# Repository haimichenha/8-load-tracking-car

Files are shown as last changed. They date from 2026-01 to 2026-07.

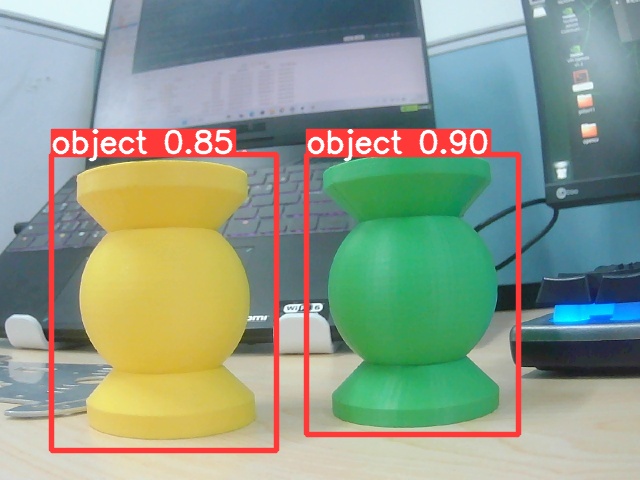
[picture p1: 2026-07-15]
ZET6 HAl/lidar_car/yolov5/runs/detect/exp12/compare.jpg

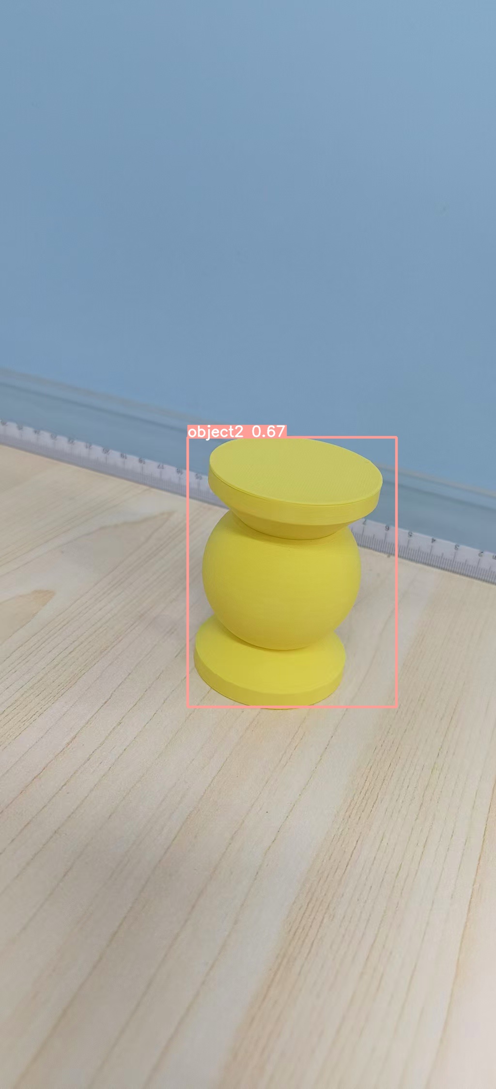
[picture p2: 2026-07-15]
ZET6 HAl/lidar_car/yolov5/runs/detect/exp6/1.jpeg

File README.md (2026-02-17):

# 八路循迹智能小车

基于 STM32F103ZET6 的八路红外循迹智能小车，采用双环 PID 闭环控制（循迹 PD 外环 + 速度 PI 内环），实现高速稳定循线、弯道自适应减速、超声波避障等功能。Keil uVision5 工程，标准库开发。

---

## 目录

- [器件材料表](#器件材料表)
- [功能特性](#功能特性)
- [项目结构](#项目结构)
- [开发历程](#开发历程)

---

## 器件材料表

### 核心控制

| 器件 | 型号/规格 | 说明 |
|---|---|---|
| 主控芯片 | STM32F103ZET6 | Cortex-M3, 72MHz, 512KB Flash, 64KB RAM |
| 小车底盘 | 定制亚克力/铝合金 | 精心挑选孔位，适配各模块安装 |

### 传感器模块

| 器件 | 型号/规格 | 说明 |
|---|---|---|
| 循迹传感器 | 亚博智能八路红外 | GPIO 直读 (PF1-PF4, PF6-PF9)，响应 <1us |
| 超声波模块 | HSR04 | 前方避障测距，非阻塞轮询，60ms 采样周期 |

### 驱动与动力

| 器件 | 型号/规格 | 说明 |
|---|---|---|
| 电机 | G310 霍尔编码器电机 | 带 AB 相正交编码器，11PPR，1:20 减速比 |
| 橡胶轮 | 48mm | 配套 G310 电机 |
| 电机驱动 | TB6612FNG | 双路 H 桥驱动，支持 PWM 调速 |

### 显示与交互

| 器件 | 型号/规格 | 说明 |
|---|---|---|
| OLED 显示屏 | 0.96 寸四引脚 | I2C 接口，128x64 分辨率，分帧刷新 |
| 蜂鸣器 | 无源蜂鸣器 | 低电平触发，PWM 驱动，支持 8 种音效 |

### 电源管理

| 器件 | 型号/规格 | 说明 |
|---|---|---|
| 锂电池 | 辰克 2800mAh | 小型号端子，紧凑安装 |
| 降压模块 | MP1584 | 电池电压降至 5V 稳压输出 |

### 辅料与连接件

| 类别 | 明细 |
|---|---|
| 螺丝紧固 | M3 螺丝、铜柱、厚螺母；M2 螺丝、螺母 |
| 连接器 | 2.54mm 排针、排母 |
| 接线 | 杜邦线、面包板、面包板跳线 |
| 被动元件 | 10uF 直插电容、100nF 贴片陶瓷电容、4.7K 上拉电阻、1K 贴片电阻 |
| 指示器件 | 直插 LED（红/绿/指示） |

---

## 功能特性

### 1. 八路循迹：GPIO 高速识别

- 8 路红外传感器通过 GPIO 直接读取（PF1-PF4, PF6-PF9），读取耗时 <1us
- 非线性权重分布：`{-12, -8, -3, -1, 1, 3, 8, 12}`，边缘传感器权重更大，提升弯道灵敏度
- 加权求和计算循迹误差，支持丢线检测与方向推断
- 传感器值：0 = 检测到黑线，1 = 白色/无线

### 2. 双环 PID 闭环控制

- **外环（循迹 PD）**：根据循迹误差计算转向输出
  - 非线性 Kp 调度：误差越大比例增益越强（err=0: 1.0x → err=12+: 4.0x）
  - D 项抑制振荡，防止蛇形走位
  - 基础参数：Kp=12.0，Kd=2.5
- **内环（速度 PI）**：确保左右轮精确跟踪目标速度
  - 位置式 PI 控制，带积分限幅（±200）
  - 参数：Kp=0.15，Ki=0.08
- 控制周期 2ms（500Hz），高频保证响应及时

### 3. 弯道自适应减速

- 根据循迹误差自动调节基础速度：误差越大，速度越低
- 减速曲线：err=2 保持 97% → err=5 降至 77% → err=10 降至 45% → err=15+ 降至 12%
- 直线基础速度 650mm/s，弯道最低 60mm/s，上限 1100mm/s

### 4. 编码器测速与里程

- MG310 霍尔编码器，11PPR x 20 减速比 x 4 倍频 = 880 脉冲/转
- 左电机 TIM2（PA0/PA1），右电机 TIM3（PA6/PA7），硬件正交解码
- 实时输出：转速 RPM、线速度 mm/s、累计距离 mm
- 左轮方向反转补偿（ENCODER_L_INVERT=1）

### 5. 超声波避障（简易实现）

- HSR04 超声波模块，PA9(Trig) / PA10(Echo)
- 非阻塞轮询模式，60ms 周期自动测距

### 6. OLED 双页面显示

- 0.96 寸 OLED，软件 I2C 驱动（PB10/PB11）
- 分帧刷新策略：运行时 1000ms / 待机 800ms，避免 I2C 通信阻塞控制回路
- 双页面切换（短按 PC5）：
  - **循迹实时页**：循迹误差 + 平均速度、目标速度 L/R、PWM L/R、传感器状态条（避障时显示距离）
  - **参数页**：Kp/Kd 值、基础速度、运行计时、超声波距离
- 启动长按进度条动画，终点到达显示完赛时间

### 7. 按键控制与交互

- **PC5 按键**：短按切换 OLED 页面，长按启动/停止循迹（带进度条反馈）
- **PC4 按键**：运行中按下 = 紧急停止；待机时按下 = 循环 LED 亮度档位（4 档：48→30→15→3）
- 软件消抖处理，按键事件队列机制

### 8. LED PWM 亮度控制

- 3 路 LED：PB9（绿）、PE0（红）、PE1（指示）
- PWM 占空比控制亮度，4 档循环（48/30/15/3）
- 运行时 LED 熄灭降低干扰，终点到达触发灯效

### 9. 蜂鸣器多音效提示

- 无源蜂鸣器 PB8，TIM5_CH3 PWM 驱动，支持频率控制
- 8 种内置音效序列：
  - **开机音**：Do-Sol-高Do 欢迎音
  - **激活提示**：短响 1 声（Sol）
  - **1 分钟提醒**：短响 2 声（Mi-Mi）
  - **终点到达**：3 声升调（Do-Mi-Sol）
  - **成功提示**：上升音阶 Do-Mi-Sol-高Do
  - **错误提示**：下降音阶 Sol-Mi-Do
  - **警告提示**：急促四连响（La x4）
  - **按键音**：极短 30ms 响

### 10. 串口调试日志系统

- 运行时日志存储到 RAM（最多 1400 条 LogEntry，约 20 秒数据 @10ms 周期）
- 停车后通过 UART4（115200 波特率）导出 CSV 格式诊断日志
- 每条记录包含：序号、测试编号、时间戳、循迹误差、传感器原始值、左右轮 PWM/速度/目标速度、控制标志位、饱和信息、动态 Kp 倍率等 22 个字段
- 支持多次测试标记（testId），方便分段分析
- 可通过宏 `LOG_ENABLE` 开关日志功能

---

## 项目结构

### 1. 主控入口与调度：`User/main.c`

`main.c` 是当前 V7 版本唯一的运行主流程入口，负责：

- 系统初始化与启动音效
- 按键事件处理（PC5 启停/切页，PC4 急停/亮度档位）
- 2ms 高频控制环（循迹 PD 外环 + 速度 PI 内环）
- 超声波避障状态机
- OLED 双页面渲染
- 运行日志记录

关键时序（主循环内）：

- **控制环**：`2ms`（`if ((nowMs - lastControlMs) >= 2)`）
- **超声波触发**：`60ms`（`OBS_PERIOD_MS`）
- **外设更新**：运行 `100ms` / 待机 `20ms`
- **OLED 刷新**：运行 `1000ms` / 待机 `800ms` / 长按提示 `150ms`
- **运行态节流**：每圈 `Delay_ms(1)`

`main()` 主流程拆解：

1. **初始化阶段**：`SysTick/按键/红外/超声波/OLED/UART4/LED_PWM/蜂鸣器/电机编码器/PI参数` 依次初始化
2. **待机阶段**：允许切页与亮度档位调整，电机保持停止
3. **启动阶段**：PC5 长按进入运行，清零里程/计时/滤波/状态机并打日志分隔标记
4. **运行阶段**：
   - 读取传感器并计算误差（含丢线恢复、终点投票、方向记忆）
   - 计算动态 `Kp` 与动态基础速度
   - 外环 PD 生成转向量，内环 PI 生成左右 PWM
   - 电机输出 + OLED 刷新 + 日志采样
5. **停止阶段**：急停/终点触发后，停止电机并导出日志

### 2. 功能-文件映射（当前主流程）

| 模块 | 主要文件 | 关键实现 | 参数/依据 |
|---|---|---|---|
| 循迹采集 | `Hardware/bsp_ir_gpio.c/.h` | `IR_GPIO_Init`、`IR_GPIO_Read` | GPIOF 8路引脚映射（PF1-PF4, PF6-PF9） |
| 循迹控制 | `User/main.c` | 加权误差、丢线恢复、交叉抑制、动态 Kp、PD 转向 | `SENSOR_WEIGHTS_V5`、`TRACK_KP/KD` |
| 速度环 | `User/main.c` | `PI_Init`、`PI_Compute`、目标速度合成、PWM 输出 | `SPEED_KP/KI`、`INTEGRAL_MAX`、`PWM_MAX/MIN` |
| 电机驱动 | `Hardware/bsp_motor.c/.h` | `Motor_SetSpeedBoth`、方向与PWM映射 | TB6612 管脚与 20kHz PWM |
| 编码器测速 | `Hardware/bsp_encoder.c/.h` | `Encoder_Init`、`Encoder_Update`、`Encoder_GetSpeedMMS` | 11PPR × 20 × 4 倍频、轮径48mm |
| 超声波避障 | `Hardware/HCSR04.c/.h` + `User/main.c` | `HCSR04_Poll`、`HCSR04_StartMeasure`、状态机接管 | `OBS_WARN_CM/OBS_AVOID_CM/OBS_EXIT_CM` |
| OLED 显示 | `Hardware/OLED.c/.h` + `User/main.c` | `OLED_ShowString` 分帧刷新，双页面显示 | `DISPLAY_PAGES=2`，按状态切页 |
| 按键输入 | `Hardware/bsp_key.c/.h`、`bsp_key2.c/.h` | `Key_Scan`、`Key2_GetEvent` | C5短/长按与 C4 事件分离 |
| LED 指示 | `Hardware/bsp_led_pwm.c/.h` | `LED_PWM_Init`、`LED_SetBrightness`、`LED_StartFinishEffect` | 待机4档亮度、终点灯效 |
| 蜂鸣器 | `Hardware/bsp_buzzer.c/.h` | `Buzzer_PlayBeep`、`Buzzer_BeepTriple`、`Buzzer_Update` | 启动/激活/急停/终点提示 |
| 串口日志 | `User/main.c` + `Hardware/bsp_usart.c/.h` | `Log_Add`、`Log_Start/Stop`、`Log_Export`、`UART4_Send_String` | `LOG_ENABLE`、`LOG_PERIOD_MS`、`LOG_MAX_ENTRIES` |

### 2.1 重点文件补充说明（你关心的模块）

- `Hardware/bsp_led_pwm.c/.h`：当前 LED 主实现，负责三路亮度 PWM、亮度档位、终点灯效。
- `Hardware/app_ui.c/.h`：历史 UI 页面框架（含陀螺仪页等），当前 V7 主流程未调用，现行显示逻辑在 `User/main.c` 内直接渲染。
- `Hardware/app_motor.c/.h`：历史运动封装（`Motion_Car_Control`），当前 V7 主流程主要直接走 `bsp_motor + bsp_encoder + main.c 内 PI`。
- `Hardware/bsp_encoder.c/.h`：编码器采样与速度/里程计算，给主循环速度环提供反馈。
- `Hardware/bsp_ir_gpio.c/.h`：循迹输入底层，8 路 GPIO 快速读取。
- `Hardware/bsp_buzzer.c/.h`：蜂鸣器音效状态机，主循环按周期调用 `Buzzer_Update`。
- `Hardware/HCSR04.c/.h`：超声波非阻塞测距，主循环轮询并驱动避障状态切换。

### 3. 参数集中位置（调参入口）

当前版本参数集中在 `User/main.c` 顶部宏区，便于赛道调参：

- **速度环参数**：`SPEED_KP`、`SPEED_KI`、`INTEGRAL_MAX`
- **循迹参数**：`TRACK_KP`、`TRACK_KD`
- **速度边界**：`BASE_SPEED_MMS`、`MIN_SPEED_MMS`、`MAX_SPEED_MMS`
- **避障阈值**：`OBS_WARN_CM`、`OBS_AVOID_CM`、`OBS_EXIT_CM`
- **日志参数**：`LOG_ENABLE`、`LOG_PERIOD_MS`、`LOG_MAX_ENTRIES`

建议调参顺序：

1. 先调速度环（确保左右轮可稳定跟踪目标）
2. 再调循迹环（Kp 响应、Kd 抑振）
3. 最后调避障阈值和基础速度

### 4. 备用/历史模块说明（当前主流程未调用）

以下文件在工程中仍可见，但**当前 V7 主流程未接入**：

- `Hardware/app_ui.c/.h`：旧版多页面 UI 框架（含陀螺仪页）
- `Hardware/app_control.c/.h`：旧版控制状态机框架（含陀螺仪输入接口）
- `Hardware/JY301P.c/.h`、`wit_c_sdk.c/.h`：陀螺仪协议与解析
- `Tracking/HW_I2C/app_irtracking/mpu6050` 等历史模块：旧方案残留

---

## 开发历程

（待补充）

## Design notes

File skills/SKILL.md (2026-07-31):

---
name: stm32f103zet6-d-mission-car
description: "Use when working on the STM32F103ZET6 land-and-air electronic-competition car for D task: gray line tracking, four-wheel TB6612 bring-up, encoders, gyro/radar pose integration, LoRa V2.3 communication, MaixCam coordination boundaries, A-to-B speed coordination, physical start buttons, staged testing, or related documentation. Read before changing car hardware code, mission behavior, pin maps, or test records."
---

# D Task Car Skill

Use this skill for the car-side STM32F103ZET6 project. The competition vehicle
is a line-following vehicle: the primary local guidance sensor is the
eight-channel gray tracking array, not a camera or an assumed lidar-only path.

## Read In This Order

1. Read `references/rules.md` before changing GPIO, TIM, PWM, encoder, UART,
   motor, or gray-tracking code.
2. Read `references/d-mission-car.md` before changing LoRa, Pi pose input,
   task buttons, state-machine behavior, coordination speed, or D-task logic.
3. Read `references/workflow.md` before wiring, flashing, bench testing, field
   testing, or interpreting logs.
4. Read `references/core.md` and `references/docs.md` when resolving source
   conflicts or updating project documentation.
5. Read `references/radar_bigturn_good_baseline_20260515.md` only for
   historical radar tuning; it never defines the current pin map or protocol.

## Mandatory Decisions

State the active mode before editing or flashing:

- `BENCH_FOUR_WHEEL`: lifted-wheel TB6612 qualification. The gray interface is
  intentionally disabled even though rear STBY is now on PB9.
- `COMPETITION_LINE_FOLLOW`: the gray module owns `PC0/PC1/PC2` as
  `AD0/AD1/AD2` address outputs and `PG0` as the selected digital `OUT`
  input. PG1 is unused. Scan and map all eight heads before controller work.

Never claim the unresolved ADC channels form an eight-position decode. Resolve
physical output mapping, thresholds, safety defaults, and documentation together.

## Operating Rules

1. Keep the car moving after a valid task request; LoRa ACKs, telemetry loss,
   and ground-station display state do not independently stop line following.
2. Start a D-task request only from the physical button on the car. The ground
   station is display and preflight-calibration only during the task.
3. Use encoder speed feedback and gyro yaw correction as assistance around the
   gray tracking controller. Do not replace the gray array with inferred pose
   or radio commands.
4. Choose A-to-B speed from measured path time with margin below the required
   15 s. Other verified sections may be faster, but only after the line,
   encoder, and braking behavior have been tested at that speed.
5. Treat `F:\keil5\stm\ZET6 HAl\lidar_car\docs\D题_通用通信与接口规范_v2.3.docx` as the communication
   authority. Online frame Version remains `0x02`; V2.3 adds the physical
   maintenance-reset handshake and supersedes V2.2 where they differ. Do not
   invent a LoRa frame, free-running transmit schedule, or task acceptance semantic.
6. Keep the MaixCam V2.3 session on the air side. The car provides
   `TaskType/MissionId` and pose; only the flight controller creates `ModeSeq`
   and controls CAMERA_MODE/ACTION. Do not route camera frames through the car.
6. Keep bench evidence separate from competition evidence. PWM register values
   show MCU output, not motor torque, wheel direction, or closed-loop quality.

## Reference Map

| Reference | Purpose |
| --- | --- |
| `references/rules.md` | Current pins, peripheral ownership, and the gray/rear-driver conflict |
| `references/d-mission-car.md` | D-task car responsibilities, coordinate contract, LoRa timing, speed policy |
| `references/workflow.md` | Bench-to-field bring-up and acceptance order |
| `references/core.md` | Source priority, evidence rules, and documentation updates |
| `references/docs.md` | Authoritative local documents and code locations |
| `references/turning-points.md` | Durable hardware and mission decisions |

Keep the entry concise. Put pin facts in `rules.md`, D-task protocol details in
`d-mission-car.md`, and test evidence in project logs rather than this file.

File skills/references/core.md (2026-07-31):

# Core Constraints

## Scope

This skill governs the STM32F103ZET6 car for the D land-and-air task. Its
responsibilities are safe motion, eight-channel gray line following, local
pose intake from the Raspberry Pi/radar stack, LoRa transmission and task
requests, plus observable test evidence. It does not decide flight control,
camera release, or ground-station mission control.

## Source Priority

Resolve a conflict in this order:

1. Current physical wiring and a repeatable observation from this build.
2. `references/rules.md` and `docs/D题小车端实施基线.md`.
3. The current STM32F103ZET6 source selected by the active CMake preset.
4. `F:\keil5\stm\ZET6 HAl\lidar_car\docs\D题_通用通信与接口规范_v2.3.docx`
   for authoritative V2.3 communication behavior. The on-wire Version field
   remains `0x02`.
5. `docs/D题 回复.txt` for official clarifications.
6. Historical MSPM0/lidar, old motor tests, chat notes, and web examples.

When hardware and code disagree, stop expansion work. Record the physical pin,
the configured peripheral mode, the expected signal, and the observed result
before changing either one.

## Current Facts And Non-Facts

- The gray module uses `PC0/PC1/PC2` as GPIO address outputs `AD0/AD1/AD2`
  and `PG0` as selected digital `OUT`; PG1 is unused. It is a 74HC4051-style
  eight-channel mux, not an ADC array. The full X1--X8 mapping, white/black
  polarity, centered `X4|X5`, and left/right error sign are verified. The
  remaining gray work is lost-line/wide-line policy and motor-actuation tests.
- Front TB6612 is the proven drive chain: PWM `PA2/PA3`, direction `PE2-PE5`,
  and `PE6` STBY. Front encoders use `TIM5 PA0/PA1` and `TIM3 PA6/PA7`.
- The present rear TB6612 bench definition uses `PE13/PE14` PWM,
  `PF1-PF4` direction, and `PB9` STBY. It has no current gray conflict, but
  four-wheel competition regression remains incomplete.
- Rear encoder pins are wired as test inputs only. Their TIM4/TIM8 hardware
  encoder initialization and direction calibration are not yet complete.
- UART5 LoRa transport is `PC12=MCU TX -> radio RX`, `PD2=MCU RX <- radio TX`,
  115200 8N1. `LineFollowMissionDebug` sends fresh `CAR_POSE (0x80)` at 10 Hz,
  sends physical-button `CAR_TASK_REQUEST (0x81)` in three car slots after a
  valid Pi calibration becomes available, receives `MISSION_STATUS (0x82)` and
  `FLIGHT_TELEMETRY (0x02)`, and emits three urgent `MISSION_ABORT (0x84)`
  copies on a task-key safety stop. The flight controller owns MaixCam
  ModeSeq/session control; do not manufacture a car-side camera interface.
- The current competition image is `LineFollowMissionDebug`: PG13 starts task
  one, PG9 starts task two, and either task key is an active-run safety stop.
  PG12 is the stopped-for-12-s, held-for-2-s maintenance key; PG10 is unused.
  A full-black A marker and fresh JY901 gate local propulsion. Pi/radar pose is
  auxiliary: it supplies a valid `CalibrationId`, coordinate display, B/A
  preparation, and delayed task coordination but never blocks local line
  following. Both tasks start at about 120 mm/s; verified flight-stage gates
  may open the approximately 180 mm/s envelope.

## Documentation And Evidence

Update the project baseline when a pin, direction polarity, timer mode, LoRa
rate, sensor polarity, speed limit, or task transition changes. A passing
stage needs a reproducible command, build/preset, wiring statement, and at
least one log, measurement, photo, or direct observation.

Keep these distinctions explicit:

- `planned`: wiring or behavior not physically verified;
- `bench verified`: isolated test only;
- `competition verified`: gray tracking and mission interfaces active on the
  intended field configuration.

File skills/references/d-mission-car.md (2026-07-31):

# D-Task Car Mission Contract

## 1. Car-Side Role

The car is responsible for physical start buttons, gray line following, local
motion safety, Pi pose intake, LoRa V2.3 transmission, calibration forwarding,
and task-request retries. The eight-channel gray module is acquired through
GPIO address outputs `AD0/AD1/AD2=PC0/PC1/PC2` plus selected digital
`OUT=PG0`; its full scan must be calibrated. The
Raspberry Pi converts radar/SLAM coordinates to the platform-center
`FIELD_GLOBAL` pose. The car MCU sends that pose over LoRa. The flight
controller alone accepts or rejects flight tasks.

During either mission, the car continues its line-following loop. A wireless
ACK, a telemetry timeout, or a ground-station UI event is not a stop command
for vehicle motion.

## 2. Coordinate And Pose Contract

- Reference point: center of the car platform, not a lidar origin, wheel axle,
  or chassis corner.
- Frame: `FIELD_GLOBAL`; car forward is `+X`, left is `+Y`, and yaw is
  counter-clockwise positive.
- Units: X/Y in cm, yaw in 0.1 degrees, velocity in cm/s if valid.
- Publish `CAR_POSE` only when position, calibration, and yaw validity bits
  are truthful. Use one nonzero `CalibrationId` for a task and never change it
  during that task.
- Pi-to-MCU local pose ingress uses UART4 (`PC11=MCU RX`) at 115200 8N1. A
  native `FIELD_GLOBAL`, position-valid, yaw-valid, calibrated pose with a
  nonzero `CalibrationId` is eligible for task coordination. Legacy
  `FA...AB` pose data remains display-only. Treat a 250 ms pose age as stale.
  Never make this input a local motor-start prerequisite: absent Pi/radar data
  defers `0x81` and coordinate assistance, but local gray/JY901 following
  remains available.

## 3. LoRa V2.3 Contract

Follow `F:\keil5\stm\ZET6 HAl\lidar_car\docs\D题_通用通信与接口规范_v2.3.docx`
exactly. Online frame Version remains `0x02`; V2.3 is the authoritative
document revision.

| Item | Car requirement |
| --- | --- |
| `CAR_POSE` type 0x80 | Broadcast at 10 Hz only while Pi pose is fresh; it is the shared wireless time base |
| `CAR_TASK_REQUEST` type 0x81 | Physical PG13 selects task 01 drop and PG9 selects task 02 dynamic landing. The local run may start without Pi; queue the same mission ID/sequence at most three times once a valid `CalibrationId` is present |
| `MISSION_STATUS` type 0x82 | Accept only the matching TaskType/MissionId. It is the authoritative one-shot stage transition |
| `FLIGHT_TELEMETRY` type 0x02 | Use ModeCode as continuous stage and lost-0x82 recovery only after this task's `0x81` ACK; it never starts or stops the car |
| Calibration type 0x83 | Accept only while car is not running; forward to Pi and ACK ground station only after Pi success ACK |
| Physical reset 0x85 | PG12 held for 2 s only after 12 s stopped broadcasts three identical `0x85` frames directly to ground. PG9 is not a maintenance key. |
| `MISSION_ABORT` type 0x84 | A second PG13 or PG9 press during an active run immediately turns motors off and sends three urgent, ACK-required abort frames |
| Car slot | 0-25 ms of each 100 ms cycle: pose, task retry, or required maintenance ACK |
| Air slot | 30-55 ms reserved for air-side response; car remains silent |
| Guard slot | 55-100 ms silent; no debug tunnel or free-running packet |

Deduplicate task requests and replies. Do not make the car stop, restart, or
perform flight decisions because an ACK arrives. Keep protocol logs compact:
`time_ms,type,seq,mission_id,crc_ok,age_ms,slot,event`.

## 4. MaixCam V2.3 Boundary

The flight controller accepts the car task, creates `ModeSeq`, and establishes
the MaixCam `CAMERA_MODE` session. The car preserves its `TaskType/MissionId`
in the V2.3 request and continues publishing pose, but never creates or
interprets `ModeSeq`, CAMERA_TARGET, CAMERA_ACTION, or CAMERA_ACTION_RESULT.
Camera ACK/timeout/target loss/result are air-side events and cannot stop or
restart the car line-following state machine.

## 5. Motion Policy

1. PG13 starts task one and PG9 starts task two only from the full-black A
   marker with fresh JY901. The same task keys are active-run safety stops.
   Do not use PG10 for task control.
2. Use gray line tracking as the primary path error. The current field image
   uses encoder LADRC inner loops for wheel speed and bounded direct JY901 yaw
   plus derived yaw-rate correction for heading. Pi/radar coordinates are
   auxiliary only: capture A when the calibrated pose is present at launch,
   use B/A for progress and stop preparation, and never feed coordinates into
   lateral control or independently stop the vehicle.
3. Measure the A-to-B course repeatedly and choose a target with margin below
   the required 15 s after the car begins moving. The target may be slower than
   later straight segments only if it still meets that deadline.
4. Start both tasks at approximately 120 mm/s. Task one may unlock the
   approximately 180 mm/s envelope only after B progress and the matched air
   task has passed `DROP_ACTION` then entered `RETURN_HOME`; task two unlocks
   at matched `INTERCEPT` or a later non-ABORT stage. Stale flight state or
   `ABORT` returns to the cooperative envelope, never stops the car.
5. Continue the full line loop while the air mission runs. The two task modes
   are selected before start, not by a ground-station control during the run.

## 6. State Outline

```text
IDLE
  -> BUTTON_TASK_SELECTED_AT_A + FRESH_JY901
  -> LINE_FOLLOW_A_TO_B + OPTIONAL_CAR_POSE_10HZ + DELAYED_TASK_REQUEST
  -> LINE_FOLLOW_REMAINING_LOOP + STATUS/POSE
  -> COMPLETE_OR_SAFE_STOP
```

Gate `BUTTON_TASK_SELECTED_AT_A` on a stable physical-button event, full-black
A marker, and fresh JY901. Gate `LINE_FOLLOW_A_TO_B` on valid gray input,
motor safety, and a selected speed profile. A valid Pi pose may add the
`CalibrationId` task request and coordinate assistance later; flight status
only adjusts the bounded speed profile and never owns the motor state machine.

## 7. Acceptance Checklist

- Gray mux address scan, all-white mask, decoded X1-X8 order, and map
  white/black polarity are measured on the competition tape.
- A-to-B repeated measurements satisfy the 15 s requirement with margin.
- Gray following remains stable at each chosen segment speed.
- When Pi pose is available, `CAR_POSE` is 10 Hz, CRC-valid, calibrated, and
  references platform center. Its absence must still allow a local button start.
- Task button produces exactly one local task selection and, once calibrated
  pose is available, exactly one task-request identity with no duplicate car
  motor action after retries or ACKs.
- LoRa slots and 5 ms protection are measured with the actual radio settings.
- Ground station shows position/status but cannot start, stop, or retune the
  car during the task.
- Flight-controller/MaixCam session evidence uses the same task type and
  mission ID as the car request; no car-side camera command exists.

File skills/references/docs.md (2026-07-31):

# Document Map

## D-Task Authority

| Path | Use |
| --- | --- |
| `F:\keil5\stm\ZET6 HAl\lidar_car\docs\D题_通用通信与接口规范_v2.3.docx` | Authoritative V2.3 frame layout, coordinate contract, LoRa slots, reliability, MaixCam boundaries, and physical maintenance reset; online Version remains `0x02` |
| `F:\keil5\stm\ZET6 HAl\lidar_car\docs\D题 回复.txt` | Official clarifications: physical car button, 15 s A-to-B, line-following freedom, communication permission, platform limit |
| `F:\keil5\stm\docs\D题_Agent修改提示词_v2.2.md` | Role-specific V2.2 implementation prompts; use B.3 for car scope and B.4 for the MaixCam boundary |
| `F:\keil5\stm\ZET6 HAl\lidar_car\docs\D题_Agent修改提示词_v2.2.md` | Project-local V2.2 car/MaixCam synchronization summary |
| `F:\keil5\stm\ZET6 HAl\lidar_car\docs\D题小车端实施基线.md` | Current car-side design decisions and unresolved hardware gates |
| `F:\keil5\stm\ZET6 HAl\lidar_car\docs\line_follow_uart_flash.md` | Verified J-Link SWD and ROM-UART flashing commands |

## Current Hardware And Test Sources

| Path | Use |
| --- | --- |
| `Hardware/bsp_motor.h` and `Hardware/bsp_motor.c` | Front TB6612 pins, PWM, direction, and STBY behavior |
| `Hardware/bsp_ir_gpio.h` and `Hardware/bsp_ir_gpio.c` | Historical PF direct-GPIO implementation; do not use as the current five-pin gray wiring source |
| `Hardware/bsp_aux_tb6612.h` and `Hardware/bsp_aux_tb6612.c` | Rear TB6612 bench-only mapping; inspect before any four-wheel test |
| `Hardware/app_four_wheel_tb6612_test.c` | Bounded four-wheel bench test behavior |
| `logs/four_wheel_tb6612_wiring_20260729.md` | Bench wiring record; not a competition wiring approval |
| `Hardware/bsp_gray_tracking.*` and `Hardware/app_gray_tracking_test.c` | Current 74HC4051-style X1-X8 address scan: PC0/PC1/PC2 drive AD0/AD1/AD2 and PG0 reads OUT |
| `docs/灰度循迹触发测试.md` | Current mux8 wiring, all-white baseline, and sequential X1-X8 test protocol |
| `scripts/analyze_gray_mux_log.ps1` | Current mux8 log analysis; use it instead of the archived ADC analyzer |
| `logs/gray_tracking_sync_20260730.md` | Driver-correction checkpoint; historical ADC logs are not current mapping evidence |

## Update Policy

Update `D题小车端实施基线.md` and `references/rules.md` together when a
physical pin, selected interface, safety gate, V2.3 mission boundary, or
mission behavior changes.
Keep the Word communication specification unchanged unless the team formally
revises the protocol. Do not treat historical test logs as a replacement for
the current pin table.

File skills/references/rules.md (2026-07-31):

---
name: stm32f103zet6-d-mission-rules
description: Current STM32F103ZET6 D-task car pin ownership and mode guards. Read before changing hardware-related code.
---

# Pin And Mode Rules

## 1. Front Drive: Competition Baseline

| Function | Pin | Peripheral / rule |
| --- | --- | --- |
| Front-left PWM | PA2 | TIM2_CH3, 20 kHz |
| Front-right PWM | PA3 | TIM2_CH4, 20 kHz |
| Front-left AIN1 / AIN2 | PE2 / PE3 | GPIO output |
| Front-right BIN1 / BIN2 | PE4 / PE5 | GPIO output |
| Front TB6612 STBY | PE6 | GPIO output; low is the safe default |
| Front-left encoder A / B | PA0 / PA1 | TIM5_CH1 / CH2 encoder interface |
| Front-right encoder A / B | PA6 / PA7 | TIM3_CH1 / CH2 encoder interface |

`PA2/PA3` are motor PWM, never USART2 default pins. If gyro UART is used,
use USART2 remap `PD5/PD6` only after verifying the board wiring.

## 2. Eight-Channel Gray Tracking: Competition Baseline

The Yahboom module uses a 74HC4051-style address selector: it has four MCU
interfaces, not eight direct GPIO inputs. Keep this ownership in every
competition image:

| Interface | Pin | Role |
| --- | --- | --- |
| Gray AD0 / AD1 / AD2 | PC0 / PC1 / PC2 | GPIO outputs; address bit0 / bit1 / bit2 selecting X1--X8 |
| Gray OUT | PG0 | GPIO input; digital value of the selected head |
| PG1 | Unused | Do not claim it as a gray input without physical wiring and a new test |
| ADC reserve | PC3 / PB0 / PB1 | Do not use unless the primary group is replaced and documented |
| Analog/DAC reserve | PA4 / PA5 | Not gray-tracking inputs |

Address `000`--`111` selects X1--X8 respectively. The 2026-07-30 mux8 evidence
log (`lidar_car/logs/gray_mux_retest_20260730-104601.log`) verifies white
`0x00` and black-line activation `X1..X8 = 0x01..0x80`, one bit per head.
On the current map, a normally centered black line is `X4|X5 = 0x18`
(`lidar_car/logs/gray_mux_center_x4_x5_20260730-110625.log`); this is the
zero point. Vehicle-left and vehicle-right probes verified `X4 = 0x08` and
`X5 = 0x10` respectively; use weights `-7/-5/-3/-1/+1/+3/+5/+7` for static
diagnostics. This sign is not yet wired to motor control.
Use `raw_mask XOR all_white_mask` to remove the module's output polarity.
The remaining gray-sensor check is the physical left/right error sign and
lost-line behavior on the actual tape. Do not use the old ADC test or old PF-based
`bsp_ir_gpio` driver; both are historical implementations.

## 3. Rear TB6612: Bench-Only Mapping

| Function | Pin | Status |
| --- | --- | --- |
| Rear PWMA / PWMB | PE13 / PE14 | TIM1_CH3 / CH4, full remap; bench only |
| Rear AIN1 / AIN2 | PF1 / PF2 | GPIO output; no current gray conflict |
| Rear BIN1 / BIN2 | PF3 / PF4 | GPIO output; no current gray conflict |
| Rear STBY | PB9 | GPIO output; no current gray conflict |
| Rear-left encoder A / B | PB6 / PB7 | Input polling only; TIM4 encoder mode pending |
| Rear-right encoder A / B | PC6 / PC7 | Input polling only; TIM8 encoder mode pending |

`FourWheelTb6612Debug` is a lifted-wheel qualification image. It must not
initialize the gray address-scan interface. A line-following mission image may use the
PB9 rear STBY only after four-wheel motion and gray-array regression evidence
exists; it must still keep all motor outputs in the safe state on fault.

Before a four-wheel competition image exists, preserve the verified PB9 rear
STBY wiring, update `bsp_aux_tb6612.*` and motor-safe defaults with any future
change, then perform direction, encoder, and gray-array regression tests.

## 4. Serial And Communication Ownership

| Link | Current ownership | Constraint |
| --- | --- | --- |
| USART1 PA9/PA10 | Diagnostic log, 115200 8N1 | Preserve for bring-up and test evidence |
| USART2 PD5/PD6 remap | Current line-follow JY901 yaw source, 9600 8N1 | `PD5=MCU TX -> JY901 RX`; `PD6=MCU RX <- JY901 TX`; do not use PA2/PA3 |
| UART4 PC10/PC11 | Pi radar/SLAM pose ingress | PC10=MCU TX reserved; PC11=MCU RX <- Pi `/dev/mcu_usb` TX; 115200 8N1 |
| UART5 PC12/PD2 | LoRa transparent wireless | Bench verified 2026-07-30: PC12=MCU TX -> radio RX; PD2=MCU RX <- radio TX; 115200 8N1 |
| USART3 PD8/PD9 remap | Conditional expansion | Keep free until LoRa/other module ownership is confirmed |

The D-task LoRa transport is assigned to UART5 by the 2026-07-30 bidirectional
fixture test. Do not concurrently attach a Pi/Nano to PC12/PD2. The Pi pose
bridge is instead assigned to UART4. The current mission controller accepts
only a fresh, calibrated native `FIELD_GLOBAL` pose with a nonzero
`CalibrationId` for wireless task coordination; legacy 14-byte `FA...AB` data
is display-only. Reject malformed input and treat age over 250 ms as stale.

Current radar-car SSH endpoint, recorded on 2026-07-30: `ubuntu@192.168.0.131`
using the local `lidar_humble_ed25519` key. It is a DHCP field address: verify
reachability and host key before every remote operation; do not hard-code it
into MCU firmware.

For the current `LineFollowMissionDebug` field image, only the direct JY901
USART2 yaw source participates in heading correction. UART4 radar pose is
coordinate/coordination assistance only: it may provide a valid task
`CalibrationId`, B-progress cross-check and A-return preparation, but never
feeds lateral control or independently stops the vehicle.

## 5. Timer Ownership

- TIM2: front PWM. Do not re-purpose its period during a motor run.
- TIM3 and TIM5: front encoders. Do not generate regular PWM from a timer in
  encoder mode.
- TIM1: rear PWM only in `BENCH_FOUR_WHEEL`; enable full remap and advanced
  timer main output when that bench image is used.
- TIM4 and TIM8: reserved for the planned rear encoder pairs. Do not claim
  closed-loop four-wheel control until these are configured and calibrated.
- TIM6/TIM7: internal scheduling candidates, no external PWM channels.

## 6. Wiring And Safe-State Rules

1. Connect every motor supply, TB6612 logic ground, encoder ground, and MCU
   ground together before testing PWM.
2. Keep both STBY pins low at reset, error, radio timeout handling, and mode
   change. Enable only after direction and PWM compare values are set.
3. Treat a changed PWM register as MCU evidence only. Verify the motor supply,
   TB6612 VM/VCC/GND, output terminals, wheel direction, and encoder response
   separately.
4. Change only one of wiring, remap, direction sign, PWM period, or controller
   gain per test round.
5. Competition line-follow task keys are **PG13 = task one** and **PG9 = task
   two**, both active low with pull-ups. A subsequent press of either key
   during an active run is a safety stop. PG10 is intentionally unused.
6. **PG12** is the active-low physical maintenance-event key. After a 2 s hold
   and continuously observed stopped state for 12 s, the MCU broadcasts the
   three specified `MAINTENANCE_RESET (0x85)` LoRa frames directly to the
   ground station. It sends no UART4 data to the radar/Pi and must not be used
   to clear a retained Pi calibration state.

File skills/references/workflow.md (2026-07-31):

---
name: stm32f103zet6-d-mission-workflow
description: Bench-to-field validation workflow for the STM32F103ZET6 D-task gray-line-following car.
---

# Bring-Up And Validation Workflow

## 1. Select The Mode

Write `BENCH_FOUR_WHEEL` or `COMPETITION_LINE_FOLLOW` in the test record. Do
not flash a bench image onto a vehicle expected to use the gray array.

## Flash The Current Competition Image

Use the verified SWD path from the `lidar_car` project root after removing
payload risk or lifting the wheels:

```bat
powershell -NoProfile -ExecutionPolicy Bypass -File "scripts\jlink_flash.ps1" -Configuration LineFollowMissionDebug -SwdSpeedKhz 50
```

This command configures, builds, downloads, compares every programmed section,
then resets and starts `LineFollowMissionDebug`. Accept the flash only when the
command exits `0` and every `compare-sections` range reports `matched`.

Use `scripts\flash_line_follow_uart.cmd COMx` only as a ROM-bootloader fallback;
it requires `BOOT0=1`, reset during connection, then `BOOT0=0` before running
the application. A missing Windows diagnostic COM port never invalidates an
otherwise successful SWD section comparison.

## 2. Bench Four-Wheel Qualification

1. Lift all wheels. Verify motor supply, 3.3 V logic, common ground, and both
   STBY lines low before reset.
2. Build and flash `FourWheelTb6612Debug`.
3. Confirm its bounded run: one-second wait, 65% PWM for four seconds, then
   coast and disable. Use `G`, `B`, and `S` only in a safe test area.
4. Record each wheel's direction and whether its encoder input changes. A
   static encoder count means no closed-loop conclusion.
5. Stop after hardware qualification. Do not add gray tracking, LoRa, or
   mission code to this image.

## 3. Competition Pin Gate

Complete all items before enabling the D-task state machine:

1. Configure PC0/PC1/PC2 as `AD0/AD1/AD2` GPIO address outputs and PG0 as
   selected digital `OUT`; PG1 is unused. With all eight heads on white, latch
   the all-white mask under actual field lighting.
2. Verify X1--X8 by scanning each 3-bit address and moving the selected
   physical position between adjacent white and the real black line. Record
   the switch, polarity, and error sign; do not use historical ADC values.
3. If four-wheel drive is required, preserve rear STBY on `PB9`, update code
   and `rules.md` if its wiring changes, then rerun the complete gray test.
4. Confirm front motor direction, encoder sign, and the safe stop path.
5. Do not use the presence of a passing bench log as proof that this gate has
   passed.

## 4. Gray Tracking Bring-Up

1. Before a physical-position mapping exists, print raw eight-channel mask,
   all-white-relative active mask, and stable mask only. Add decoded L1-L8
   states, weighted error, line-lost state, target speed, left/right targets,
   and output limits only after the mapping is verified.
2. Verify sensor order with per-position map-white/map-black pairs. Do not
   tune PID until the available inputs produce repeatable contrast and map to
   physical positions; ADC raw values alone are not a decode.
3. Establish a low-speed straight-line baseline, then gentle curves, then the
   tightest turn on the field. Tune the sensor threshold/polarity and steering
   sign before increasing speed.
4. Use encoder speed feedback as the inner loop. Apply gyro yaw correction as
   a bounded correction; gray error remains the path-following reference.
5. Define an explicit lost-line action with bounded speed and timeout. Never
   use a radio ACK or ground-station command as line-following control.

## 5. D-Task Coordination

1. At the physical car button, create one task request and start the car.
2. Measure A-to-B path time. Set its target so worst-case measured time remains
   below 15 s with margin; coordination may be slower than other sections but
   cannot violate the deadline.
3. After B, use separately tested faster limits only where gray tracking,
   stopping distance, and payload/platform stability permit them.
4. Keep the vehicle following the complete line loop while the air vehicle
   handles its own mission. Do not stop the car after a wireless ACK.
5. Run the LoRa timing from fresh `CAR_POSE` receipt/transmit timing, not from
   a free-running debug timer. See `d-mission-car.md`.

## 6. Required Evidence Per Stage

| Stage | Minimum evidence |
| --- | --- |
| Pin change | Updated table, build preset, and a signal or observation |
| Motor direction | Wheel, command sign, physical direction, encoder sign |
| Gray tracking | L1-L8 mapping, polarity, error sign, lost-line behavior |
| A-to-B | Distance/course version, repeated time measurements, selected limit |
| LoRa | Frame type, sequence, CRC result, timestamp/age, slot timing |
| Mission button | Task type, mission ID, retry count, no duplicate trigger |

On any unsafe, stale, or contradictory result: stop the motor outputs, retain
the log, and return to the earliest failed stage.

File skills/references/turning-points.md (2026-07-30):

# Durable Decisions

| Decision | Status | Consequence |
| --- | --- | --- |
| Primary local guidance is gray tracking | Confirmed | Use mux address outputs AD0/AD1/AD2 on PC0/PC1/PC2 plus selected OUT on PG0 in every competition image; X1-X8, white/black polarity, and X4/X5 error sign are verified |
| Gray interface correction | Confirmed from YB-MVX05-V1.0 board/silkscreen | PC0/PC1/PC2 are not ADC inputs; they select the module's 74HC4051-style X1-X8 output. Historical ADC logs are invalid mapping evidence |
| Front TB6612 is the motion baseline | Confirmed | Preserve PA2/PA3, PE2-PE6, TIM5 and TIM3 ownership |
| Four-wheel rear TB6612 mapping uses PF1-PF4 directions and PB9 STBY | Bench-only | No gray pin conflict; four-wheel competition regression remains pending |
| Rear PWM moved to TIM1 PE13/PE14 | Bench verified at MCU output level | Requires a rear-STBY remap for competition |
| Rear encoders PB6/PB7 and PC6/PC7 | Wired/test-input stage | Hardware TIM4/TIM8 encoder mode and sign calibration remain pending |
| Car starts tasks from physical buttons | D-task requirement | Do not add ground-station task-start control |
| Car sends pose at 10 Hz as LoRa time base | V2.2 requirement | Do not transmit arbitrary free-running telemetry |
| MaixCam session ownership | V2.2 requirement | Flight controller creates ModeSeq and controls camera; car only preserves TaskType/MissionId and keeps following the line |
| A-to-B is coordinated but deadline-bound | D-task requirement | Measure and preserve margin below 15 s; do not label it merely “slow” |
| First field line-follow image uses PG10 and frozen logs | One lap passed; A auto-stop pending | `LineFollowJY901Debug` completed one physical lap at 600 mm/s nominal speed with fresh direct JY901 and frozen evidence. It was manually stopped because the curved A-end marker did not sustain stable `0xFF`; repair the terminal-marker policy and repeat before increasing speed |

Whenever a row changes, update `rules.md`, the project baseline document, and
the relevant build/test evidence in the same change.

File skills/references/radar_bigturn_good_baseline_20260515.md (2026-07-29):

# 2026-05-15 雷达大转弯回原点稳定版记录（历史只读基线）

> **当前项目边界（2026-07-26）**：本文件仅保留树莓派/雷达侧的历史算法、部署和日志经验；不定义 STM32F103ZET6 的 UART、TIM、GPIO、PWM、编码器或电机接线。当前硬件 pin-map 必须以 `rules.md` 为准。

## 1. 记录目的

本文件记录 2026-05-15 最近一轮对树莓派雷达 / Cartographer 有效的修改思路、具体修改点、涉及函数、验证结果和回退路径。

当前结论：雷达侧已经从“静止/大转弯后 10~30cm 级漂移不可接受”优化到“大转弯一圈返回后误差很小、可进入下一阶段”的状态。后续不要再大幅修改雷达参数，除非先复制当前基线并保留回退路径。

## 2. 当前雷达侧正式基线

本地当前只读指针：

```text
logs/rpi_lidar_good_min_score_078_20260515_143748_READONLY/
logs/CURRENT_LIDAR_BASELINE.txt
```

本地正式包：

```text
logs/rpi_lidar_good_min_score_078_20260515_143748.tar.gz
```

SHA256：

```text
0df93bb6beb69556b14fc8216c08070931923124121328918abc6fbb27c50629
```

树莓派正式包：

```text
/home/ubuntu/codex_lidar_watch/snapshots/good_bigturn_micro_20260515_041241.tar.gz
```

## 3. 有效修改思路

### 3.1 先解决近点污染

早期日志中原始点云出现过 `0.15m ~ 0.18m` 近点。结合小车底座、线材、手、边缘遮挡等因素，近点容易把 scan matching 拉偏。

有效策略：

```lua
TRAJECTORY_BUILDER_2D.min_range = 0.8
```

含义：小于 `0.8m` 的点不参与 Cartographer 2D 匹配/建图。

### 3.2 保留足够侧向/后向特征，避免大转弯后匹配丢约束

先前后方过滤较狠：`front_half=120deg, rear_min=1.15m, rear_keep_every=3`。大转弯/180° 后，侧后方特征会变成下一段行驶的重要环境参考，过滤过狠会让转头后 x/y 位姿更容易漂。

当前有效策略：

```text
front_half=150deg
front_min=0.80m
rear_min=1.00m
rear_keep_every=2
```

效果：大转弯后可用环境特征更多，回原点误差明显减小。

### 3.3 收紧局部匹配的平移自由度，不让“大转头”被估计成“大平移”

当前有效 Cartographer 局部匹配参数：

```lua
TRAJECTORY_BUILDER_2D.use_online_correlative_scan_matching = false
TRAJECTORY_BUILDER_2D.real_time_correlative_scan_matcher.linear_search_window = 0.03
TRAJECTORY_BUILDER_2D.ceres_scan_matcher.translation_weight = 25.
TRAJECTORY_BUILDER_2D.ceres_scan_matcher.rotation_weight = 90.
TRAJECTORY_BUILDER_2D.motion_filter.max_angle_radians = math.rad(0.5)
```

有效性：

- `20/80` 已经可用；
- 微调到 `25/90` 后，用户现场确认“从角落二维码返回，误差很小”，因此 `25/90` 替换为新基线。

### 3.4 减少 ROS2 DDS 网络发现/SSH/热点对本机 ROS 图的影响

树莓派上的雷达、IMU、Cartographer、test01 都在本机运行，不需要 ROS 跨网络发现。

已在启动脚本和 `/etc/rc.local` 中加入：

```bash
export ROS_LOCALHOST_ONLY=1
```

作用：降低 ROS2 DDS 网络发现负载，减少联网/SSH 时对实时性和 CPU 的干扰。

### 3.5 修复 Cartographer 启动偶发 IMU fatal

问题现象：

```text
imu_tracker.cc: Check failed: (orientation_ * gravity_vector_).z() > 0. (0 vs. 0)
```

原因：Cartographer 启动太早时，WIT IMU 可能还没输出有效重力向量，导致初始化失败。

修复：在 launch 中用 `TimerAction(period=8.0)` 延迟启动：

```text
test01
cartographer_node
occupancy_grid_node
```

先启动：

```text
sllidar_node
wit_ros2_imu
robot_state_publisher
```

等 IMU / scan 稳定后再启动 Cartographer。

### 3.6 低负载日志与回修标记

不再让抓取脚本每条记录都 fsync，避免日志本身制造卡帧。

新增纯日志标记：

```text
pose_settle_warn
```

默认触发：最近 `10s` 内 pose 的 x/y 合成范围 `>=10cm` 或 yaw 范围 `>=3°`。用于后续分析“到点后静止回修”，不影响雷达输出，不控制小车。

## 4. 具体修改文件与函数

### 4.1 `scripts/rpi_sector_scan_filter.py`

角色：`/scan_raw -> /scan` 的扇区化 LaserScan 过滤节点。

有效修改：

1. 默认参数改为大转弯友好版：

```python
--front-half-deg default 150
--front-min-range default 0.80
--rear-min-range default 1.00
--rear-keep-every default 2
```

2. 新增/修改函数与逻辑：

```python
SectorScanFilter._ensure_geometry_cache(msg)
```

作用：缓存每个 beam 属于前方还是后方的判断，避免每帧重复角度计算，降低 Pi 负载。

```python
SectorScanFilter.on_scan(msg)
```

作用：按缓存后的扇区 mask 过滤近点/后方降采样，发布过滤后的 `/scan`。

```python
build_parser()
```

作用：提供环境变量可覆盖的默认过滤参数。

### 4.2 `scripts/rpi_light_pose_capture.py`

角色：低负载记录 `/pose`、`/tf`、`/scan_raw`、`/scan`、`/imu`。

有效修改：

```python
Cap.write(rec)
```

不再每条记录都 `fsync`，改为默认 `flush=1s`、`fsync=5s`，减少磁盘 IO 卡顿。

```python
Cap.on_pose(msg)
```

新增 `pose_hist` 窗口，并在 10s 内 x/y 或 yaw 回修超过阈值时写入：

```text
pose_settle_warn
```

### 4.3 `scripts/rpi_scan_timing_monitor.py`

角色：低负载 timing 摘要监测脚本。

关键函数：

```python
TopicStats.add_scan(...)
TopicStats.add_pose(...)
Monitor.flush_window()
Monitor.on_pose(...)
```

用途：记录 `/scan_raw`、`/scan`、`/imu`、`/pose` 的 1 秒窗口摘要，帮助判断 scan 卡帧、TF/pose 延迟、静止回修。

`Monitor.on_pose(...)` 新增 `pose_settle_warn` 标记。

### 4.4 `scripts/deploy_lidar_lowload_monitor.ps1`

角色：把低负载脚本和 sector filter 部署到树莓派。

关键动作：

```text
上传 rpi_sector_scan_filter.py
上传 rpi_light_pose_capture.py
上传 rpi_scan_timing_monitor.py
安装 sector_scan_filter executable
生成 start_scan_timing_monitor.sh
生成 start_light_capture_lowload.sh
```

### 4.5 `scripts/deploy_lidar_imu_start_delay.ps1`

角色：给 launch 增加 Cartographer 延迟启动保护。

核心修改：在 `test_grapher_3.launch.py` 中加入：

```python
from launch.actions import TimerAction

cartographer_start_delay = TimerAction(
    period=8.0,
    actions=[
        test01_node,
        cartographer_node,
        occupancy_grid_node,
    ],
)
```

### 4.6 树莓派 Cartographer 配置 `test02.lua`

路径：

```text
/home/ubuntu/cartographer/install/fishbot_grapher/share/fishbot_grapher/config/test02.lua
```

当前关键参数：

```lua
TRAJECTORY_BUILDER_2D.min_range = 0.8
TRAJECTORY_BUILDER_2D.max_range = 8.
TRAJECTORY_BUILDER_2D.use_imu_data = true
TRAJECTORY_BUILDER_2D.use_online_correlative_scan_matching = false
TRAJECTORY_BUILDER_2D.real_time_correlative_scan_matcher.linear_search_window = 0.03
TRAJECTORY_BUILDER_2D.real_time_correlative_scan_matcher.translation_delta_cost_weight = 100.
TRAJECTORY_BUILDER_2D.real_time_correlative_scan_matcher.rotation_delta_cost_weight = 1e-1
TRAJECTORY_BUILDER_2D.ceres_scan_matcher.translation_weight = 25.
TRAJECTORY_BUILDER_2D.ceres_scan_matcher.rotation_weight = 90.
TRAJECTORY_BUILDER_2D.motion_filter.max_angle_radians = math.rad(0.5)
POSE_GRAPH.optimize_every_n_nodes = 90
POSE_GRAPH.constraint_builder.min_score = 0.78
```

### 4.7 树莓派启动文件 `/etc/rc.local`

有效修改：

```bash
export ROS_LOG_DIR=/home/ubuntu/cartographer/log
export ROS_LOCALHOST_ONLY=1
export FISHBOT_POSE_BIAS_X_CM=0
export FISHBOT_POSE_BIAS_Y_CM=0
export FISHBOT_POSE_BIAS_YAW_DEG=0
export FISHBOT_ORIGIN_LOCK_DELAY_S=45
ros2 launch fishbot_grapher test_grapher_3.launch.py &
```

## 5. 验证证据

### 5.1 用户现场反馈

- 大转弯一圈回来后定位准确；
- 从角落二维码返回，误差很小；
- `25/90` 微调版比 `20/80` 更好，因此替换为新基线；
- 当前误差可接受，可进入下一阶段。

### 5.2 现场日志检查

微调版日志：

```text
/home/ubuntu/codex_lidar_watch/logs/restart_bigturn_micro_20260515_040347.log
```

关键结论：

```text
scan rate: 10.01Hz
imu rate: 10.04Hz
pose jump blocked: 未出现
scan_filter 平均耗时: 约 8~9.7ms
Cartographer constraints: score 最低约 75%，平均约 80%+
```

后续又一次转一圈回来，当前 15 秒静止窗口：

```text
map->odom: 0.0cm 变化, yaw 0.0°
odom->base_link: 合成变化约 1.42cm, yaw 约 0.20°
```

`pose_settle_warn`：未触发。

## 6. 回退路径

### 6.1 当前正式基线

```text
logs/rpi_lidar_CURRENT_GOOD_READONLY/
logs/rpi_lidar_good_bigturn_micro_20260515_121238/
/home/ubuntu/codex_lidar_watch/snapshots/good_bigturn_micro_20260515_041241.tar.gz
```

### 6.2 上一个正样本，仅作为历史备份

```text
logs/rpi_lidar_good_bigturn_20260515_120002/
/home/ubuntu/codex_lidar_watch/snapshots/good_bigturn_20260515_040006.tar.gz
```

### 6.3 关键远程回退目录

```text
/home/ubuntu/codex_lidar_watch/rollback/before_bigturn_micro_20260515_040320/test02.lua
/home/ubuntu/codex_lidar_watch/rollback/before_lowload_monitor_20260515_042754
/home/ubuntu/codex_lidar_watch/rollback/before_rclocal_localhost_20260515_041908/rc.local
```

## 7. 后续边界

1. 不要继续大幅调雷达参数。
2. 雷达侧当前只允许：日志标记、只读抓取、轻量监测。
3. 若再次调 `min_range`、扇区过滤、Ceres 权重、motion_filter、pose_graph，必须先复制当前基线并记录回退路径。
4. 下一阶段主线应转向：
   - MSPM0 到点后稳定窗口；
   - 大转弯后稳定门控；
   - 轮式里程计 / 编码器融合；
   - 全局 map 坐标与车体系误差控制链。
5. 当前 `lidarCar/empty.c` 中若存在“到点稳定窗口”草稿，属于 MCU 控制侧，不属于本雷达侧基线；未烧录前不影响实车。

## 8. 学习卡

- 组件：Cartographer + sector scan filter + test01 pose bridge
- 角色：提供小车全局/局部位姿，输出给 MSPM0 用于导航控制
- 输入：`/scan_raw`、`/imu`、TF、Cartographer 配置
- 输出：`map->odom`、`odom->base_link`、`/pose`、UART 位姿帧
- 已解决问题：近点污染、大转弯后 x/y 漂移、Cartographer IMU 启动 fatal、日志/网络负载干扰
- 剩余风险：到点后 Cartographer 可能短暂回修；大转弯后 x 可能有小瞬态漂移
- 检查问题：如果小车已经物理到达起点，但雷达 10 秒后回修了 12cm，应该继续调雷达参数，还是让 MCU 的到点稳定窗口吸收这段回修？

## 9. 2026-05-15 14:37 连续两次二维码路线验证（min_score=0.78）

### 9.1 保存位置

```text
logs/return_qr_xdrift_root_20260515_143748/
logs/rpi_lidar_good_min_score_078_20260515_143748_READONLY/
logs/rpi_lidar_good_min_score_078_20260515_143748.tar.gz
logs/CURRENT_LIDAR_BASELINE.txt
```

包 SHA256：

```text
0df93bb6beb69556b14fc8216c08070931923124121328918abc6fbb27c50629
```

树莓派原始目录：

```text
/home/ubuntu/codex_lidar_watch/logs/return_qr_xdrift_root_20260515_143748
```

### 9.2 本轮现场结论

用户连续跑了两个二维码路线并返回起始点，现场反馈两次返回误差都很小；第二次把小车放到真实起始点中心后，日志最终误差仍在约 20cm 内。

本轮最终日志：

```text
last_pose = x +8cm, y +13cm, yaw -3.933deg
final_error = 15.26cm
```

停车后稳定窗口：

```text
last 10s: x range 1cm, y range 0cm, yaw range 0.449deg
last 30s: x range 4cm, y range 1cm, yaw range 0.785deg
```

### 9.3 约束证据

`min_score=0.78` 后，Cartographer 日志中没有接受低于 78 的约束。拉取到的节点日志整体统计：

```text
constraint count = 555
min score = 78.0
max score = 89.6
avg score = 83.23
max accepted translation = 0.22m
low score <78 = 0
```

这说明之前 `score≈77.1`、`translation≈4.06m` 这类弱约束大错配已经被挡掉。当前仍存在 0.18~0.22m 的边缘约束，但最终回起点误差已经明显下降。

### 9.4 当前调参判断

当前版本应作为下一阶段候选稳定版：

```lua
POSE_GRAPH.constraint_builder.min_score = 0.78
```

不要继续大幅改 `translation_weight`、`rotation_weight`、`motion_filter`、`optimize_every_n_nodes`。如果后续重复长路线仍超过 15~20cm，才考虑小步试 `min_score=0.79`，并必须保留当前 `0.78` 回退包。

## 10. 2026-05-15 连续三个二维码路线现场确认

用户现场确认：当前 `min_score=0.78` 版本连续跑三个二维码路线，返回起始点都准确。结合第 9 节完整抓取日志，当前雷达侧版本从“候选稳定版”升级为“正式 known-good 基线”。

代码只读快照：

```text
logs/rpi_lidar_20260515_three_qr_min_score_078_CODE_READONLY/
```

当前结论：

1. 保留 `POSE_GRAPH.constraint_builder.min_score = 0.78`。
2. 保留 `min_range=0.8`、扇区过滤、大转弯友好参数、低负载抓取脚本。
3. 暂停继续大幅调整雷达侧 Cartographer 参数。
4. 后续若再次出现长路线回起点误差超过 15~20cm，才允许小步 A/B 测试 `min_score=0.79`；测试前必须复制当前基线。
5. 下一阶段重点转向 MCU 控制侧：到点稳定窗口、路径点跟踪、编码器/IMU 短程协作。

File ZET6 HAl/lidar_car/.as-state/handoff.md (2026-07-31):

# Electrical Contest Integration Handoff

## Active scope

Prepare the STM32 car firmware and its local documentation for the electrical
contest car-aircraft integration.  The authoritative requirement sources are
the V2.3 protocol DOCX, `docs/\u4efb\u52a1\u8981\u6c42.png`, and `docs/D\u9898 \u56de\u590d.txt`.

## Known implementation evidence

- PG12 is the maintenance-reset key.  PG13 starts task 1 and PG9 starts task
  2; a second press of either task key requests the local emergency stop.
- The car MCU parses V2.3 mission status (`0x82`) and flight telemetry
  (`0x02`). A task session now requires three successfully sent, current-
  calibration `0x80 CAR_POSE` frames before its three-slot `0x81` retry
  sequence; UART5 RXNE buffering protects the air ACK window. MCU-local
  calibration (`0x83`) and maintenance reset (`0x85`) do not need a Pi return
  channel.
- Pi/radar input remains raw inside the MCU. Only outgoing LoRa `0x80 CAR_POSE`
  applies `X_lora=-(X_pi-13 cm)+DeltaX`, `Y_lora=-Y_pi+DeltaY`, and
  `yaw_lora=yaw_pi`. This mapping is never fed back into line following, JY901,
  encoder, or raw radar state.
- Current cooperative target speeds are 130 mm/s for task 1 and 150 mm/s for
  task 2. Task 2 alone can use up to 55% positive PWM (task 1 remains 45%) to
  provide B-point margin when the LADRC output is saturated.
- The default flash route is J-Link SWD at 50 kHz through
  `scripts/jlink_flash.ps1 -Configuration LineFollowMissionDebug -SwdSpeedKhz 50`.
  On 2026-08-01 it connected at 3.30 V, programmed and compare-verified every
  image section, reset the MCU, and COM13 `P` confirmed the running image.
- Radar coordinates are auxiliary progress/preparation evidence. Gray line,
  JY901 heading, and encoder distance remain the motion and stop authorities;
  the car may run a local lap with no radar/Pi input.
- The confirmed field policy is: PG13/PG9 do not wait for Pi, radar, or a
  CalibrationId. If fresh raw pose and MCU-local calibration become available
  while the car is already following the line, the MCU may then establish
  `0x81` cooperation; otherwise it continues locally. The protocol forbids
  fabricating a zero or stale CalibrationId solely to start aircraft
  coordination.
- A stopped car can replace its local calibration for debugging with a new
  `0x83` request sequence. The new Delta is complete relative to raw Pi pose,
  not additive. The current image was physically flashed and boot-checked on
  2026-08-01. The user also reports a successful car-aircraft joint test;
  preserve the next radio capture before treating this as scored evidence.

## Open scoring risks

- The current firmware audit must enforce a 90-second lap policy and record
  the task-2 B-point 15-second milestone. Local vehicle motion must remain
  available without radar/Pi; a scored aircraft session still needs a valid
  calibrated pose and the corresponding wireless task evidence.
- Task 2 must remain at cooperative speed through platform landing and its
  five-second dwell; only the post-platform-takeoff aircraft stage may unlock
  the fast envelope.
- Pi raw-pose deployment, aircraft firmware, air-radio forwarding,
  payload/landing behavior, and graphical ground station are external owners.
  Their absence is a field-test blocker, not a result that MCU code can claim.
- The one-way Pi-to-MCU path is a compatibility field-test topology. It does
  not close the published V2.3 Pi calibration/ACK transaction or prove the
  physical platform-center requirement; do not record a strict scoring pass
  without those external evidence gates.

## Historical archive

The earlier L298N wheel-direction work remains in `state.json` and
`learning.json` as historical evidence.  It is not part of the current
contest-readiness acceptance decision.

## Next minimum action

Run one controlled straight-line field case from A with PG13 or PG9, then
capture `CALIBRATED 0x80 x3 -> 0x81 x3 -> air 0x11 ACK`, `radio_uart_err=0`,
and the frozen line-follow log before changing base speed, PWM limits, or turn
parameters. Preserve paired Pi-input/LoRa-output frames proving
`X_lora=-(X_pi-13 cm)+DeltaX`, `Y_lora=-Y_pi+DeltaY`, and `yaw_lora=yaw_pi`.

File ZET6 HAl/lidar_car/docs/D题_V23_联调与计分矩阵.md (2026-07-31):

# D 题 V2.3 联调与计分矩阵

更新时间：2026-08-01

> 本文是当前唯一的赛题联调和计分验收入口。它不把“MCU 能编译”或“小车
> 能循迹”写成“赛题已经通过”。历史日志可作为证据索引，不能替代本轮现场记录。

> **先读合规状态：** [D题_赛题合规差距清单_20260731.md](D题_赛题合规差距清单_20260731.md)
> 是本镜像进入正式计分联调前的强制门槛。本文记录的 MCU 本地校准路径可用于当前
> 单向 Pi 硬件的台架和车端联调；在 G1--G7 未关闭前，它不能替代空侧实际任务、
> 视频和地面站证据，也不能作为无人机任务已得分的结论。

## 权威边界

| 主题 | 权威来源 | 本仓库可验证范围 |
| --- | --- | --- |
| 通信帧、时隙、校准 | `D题_通用通信与接口规范_v2.3.docx` | 小车 MCU UART4/UART5 |
| 任务和评分 | `任务要求.png`、`D题 回复.txt` | 按键、循迹、速度、计时 |
| 飞行、投放、着陆 | 飞控、机载 ESP32、MaixCam、现场视频 | 不在本仓库 |
| 图形地面站 | 地面站工程、截图和录像 | 不在本仓库 |

题目分值：任务一 60 分、任务二 20 分、图形地面站 15 分、其他 5 分、报告
20 分，合计 120 分。当前状态为“准备联调”，不是“已得分”。

## 当前镜像

| 预设 | 雷达/Pi 是否阻止循迹 | UART `S` | 使用限制 |
| --- | --- | --- | --- |
| `LineFollowMissionDebug` | 否，PG13/PG9 可无雷达本地循迹 | 禁用 | 当前小车端候选镜像；本地循迹可验，正式计分仍受合规清单约束 |
| `LineFollowJY901Debug` | 否 | 启用 | JY901/灰度调试，不用于正式计分 |
| `LineFollowNoGyroDebug` | 否 | 启用 | 组件诊断，不用于正式计分 |

当前 `LineFollowMissionDebug`：任务一 `130 mm/s`、任务二 `150 mm/s`、
`LINE_REQUIRE_GYRO_FOR_START=1`、`LINE_REQUIRE_CALIBRATED_POSE_FOR_TASK_START=0`、
`LINE_ENABLE_UART_MANUAL_STOP=0`。PG12 固定为停车后短按。严格外部位姿/空侧 ACK 起跑门保留为专项取证选项，
不是默认条件，不能因雷达故障阻止本地车辆循迹。

## 车辆控制权责

| 功能 | 主依据 | 雷达/Pi 角色 | 禁止行为 |
| --- | --- | --- | --- |
| 横向循迹 | 八路灰度 | 无 | 不用雷达 X/Y 直接转向 |
| 转弯航向 | 直接接入 JY901 yaw/yaw-rate | 无 | 不融合雷达 yaw 控制 |
| 速度与路径 | 前轮编码器、LADRC、灰度误差 | B/A 进度旁证 | 雷达不得单独加速或停车 |
| A 点停车 | 灰度 A 标记、累计航向、编码器路径 | 只预备回归窗口 | 雷达帧不得单独停车 |
| 无人机协同 | 合法 `0x81/0x82/0x02` 会话 | Pi 只单向提供原始位姿；MCU 本地校准后发布 `CAR_POSE/CalibrationId` | 无 Pi 时延后协同，不阻止车辆循迹或伪造 `0x81` |

失线后小车按最近四帧方向进入 `LOST_HOLD` 搜线；只有中心传感器捕获并连续 10 个
20 ms 控制周期（约 200 ms）稳定重获后才恢复，超过 12 s 才安全停止。内侧轮允许
有限反向目标扩大急弯差速，前轮编码器仍是速度反馈。

## 按键与安全

| 按键 | 当前行为 |
| --- | --- |
| PG13 | 任务一启动；运行中再次按下为物理急停 |
| PG9 | 任务二启动；运行中再次按下为物理急停 |
| PG12 | 当前标准：车辆停止后低有效短按（50 ms 消抖）即可清除本地校准并直接广播三帧 `0x85`；超过三帧发送窗口后可再次短按，生成新的 ResetId |
| PG10 | 不参与启动、停车或任务 |

正式镜像禁用串口 `S` 停车；串口 `P/F/H` 仅用于读取状态和冻结日志。安全急停必须
在证据中标明，不得混同为正常任务完成。

### PG12 维护复位标准

本工程只保留一种 PG12 物理触发语义：车辆未运行时低有效短按，经过 50 ms 消抖即发起
本地维护复位。MCU 清除本地 Delta、`CALIBRATED` 与 CalibrationId，随后在三个连续车端
时隙广播同一 ResetId/Seq/Payload 的 `0x85`；三帧完成后可再次短按。

权威 V2.3 附录中的“静止 12 s + 长按 2--3 s”是外部赛题条款，不是当前固件的可选
构建模式，也不会在本工程中与短按混写为默认行为。它与当前单向 `Pi TX -> MCU RX`
硬件下的复位所有权差异，继续在合规清单 G3 中单独记录；短按日志不得伪称为长按验收
证据。

## 雷达坐标与地图

下表是 Pi 本地原始地图/安装参考，不能直接称为本轮 `FIELD_GLOBAL` 绝对坐标。
每次 `0x83` 的 `DeltaX/DeltaY` 仅存入 MCU RAM，并且只用于 LoRa 出站坐标；
Pi 原始输入和 MCU 内部雷达辅助始终保持未校准值。现场证据必须同时记录
`CalibrationId`、Delta 与校准后的三帧出站位姿。

| 点位 | 本地参考 X (cm) | 本地参考 Y (cm) | 航向参考 | 车辆用途 |
| --- | ---: | ---: | --- | --- |
| A | 0.0 | 0.0 | 约 0° | 起跑与灰度终点参考 |
| B | -151.3 | -8.1 | 约 0° | B 进度交叉检查 |
| C | -165.7 | 150.7 | 约 180° | 路线显示/方向核对 |
| D | -16.5 | 164.2 | 约 180° | 路线显示/飞行阶段证据 |

B/C/D 几何与约 150 cm x 150 cm 跑道相符。雷达 B 辅助要求距起跑 A 至少 155 cm
且连续两帧；编码器约 1550 mm 是不依赖雷达的后备进度。二者都不直接停车。

当前硬件中 Pi 到 MCU 的 UART4 链路为 `Pi TX -> MCU RX`，只传送原始位姿。
本轮空侧坐标约定为 MCU 对 LoRa 出站 `CAR_POSE` 仅执行一次镜像和平移：

`X_lora = -(X_pi - 13 cm) + DeltaX`

`Y_lora = -Y_pi + DeltaY`

`yaw_lora = yaw_pi`

X 轴先减固定 `13 cm`，再镜像 X/Y，最后叠加 `DeltaX/DeltaY`；内部原始
Pi/radar 坐标、JY901 和编码器逻辑均不应用这些变换。现场要同时抓 Pi 输入帧和 LoRa 出站帧逐帧验证该
公式，不能只验证“校准前后差值”。Pi 不发送校准 ACK；`DeltaX/DeltaY/CalibrationId`
当前归 MCU RAM 所有。

## V2.3 协同与校准

| 消息 | 小车端行为 | 最低通过证据 |
| --- | --- | --- |
| `0x80 CAR_POSE` | Pi UART4 原始位姿 -> MCU -> LoRa；仅出站应用 `X=-(X_pi-13 cm)+DeltaX,Y=-Y_pi+DeltaY,yaw=yaw_pi`，车端 10 Hz 时隙 | 新鲜度、CRC/长度/乱序、`CAR_RUNNING`、原始/出站逐帧公式 |
| `0x81 TASK_REQUEST` | PG13/PG9 会话建立后，先成功发送 3 帧当前 `CalibrationId` 的 `CALIBRATED 0x80`，再在三个车端槽重发；本地已起步时这些位姿同时带 `CAR_RUNNING` | `0x80 x3 -> 同 Seq/Payload 0x81 x3 -> 空侧 ACK`、会话匹配 |
| `0x82` / `0x02` | 更新匹配会话的阶段与速度门 | Stage、ModeCode、SourceTimeMs |
| `0x83 CALIBRATION_SET` | 地面 -> MCU 本地 RAM -> 地面 ACK；停车时的新请求 Seq 可完整替换旧 Delta，不累加 | ACK、三帧同 ID 和坐标平移校验 |
| `0x84 MISSION_ABORT` | 二次任务键急停后紧急通知 | 三帧、ACK/超时记录，不延迟关电机 |
| `0x85 MAINTENANCE_RESET` | 停车后 PG12 短按，本地清除并三帧广播，不访问 Pi | 同 ResetId/Seq；地面站随后以新 Seq/CalibrationId 的 `0x83` 重校准 |

MCU 的协同就绪条件是新鲜的原始 `FIELD_GLOBAL` 位姿
`POSITION_VALID|YAW_VALID`，并且 MCU 本地已有固定非零的 `CalibrationId`。
入站 Pi 帧不需要、也不应承担 `CALIBRATED`。该条件用于可靠建立 `0x81` 和可选
雷达辅助，不是本地小车循迹启动条件。PG13/PG9 已进入本地循迹后才满足该条件时，MCU
可以补发 `0x81`，但不会重新启动、减速或停止车辆。旧 `FA...AB` 是原始位姿
迁移数据；只要新鲜度和本地校准状态满足，可用于出站显示，但不替代正式 V2.3 输入验收。

当前车端在任务会话内只对 UART5 成功送出的 `0x80` 计数；校准 ID 改变、位姿失鲜或
在前导中插入地面 ACK 时清零。达到三帧后才允许 `0x81` 入队，因此按键到首个任务帧
会增加最多约 300 ms，但本地电机不会等待。UART5 RX 使用中断环形缓冲，避免任务发送后
的诊断串口输出覆盖空侧 ACK 接收窗口。

## 速度、阶段与计时

| 项目 | 当前车端策略 | 必须留存的日志 |
| --- | --- | --- |
| 任务一 A-B | `130 mm/s` 协同包络 | `motion_start`、B、`0x81`/ACK、飞行阶段 |
| 任务一加速 | 过 B、见 `DROP_ACTION(6)`、进入 `RETURN_HOME(11)` 后 | `coord_speed_unlocked` |
| 任务二起步 | `150 mm/s` 协同包络；前轮 LADRC 正向上限 `55%`（任务一保持 `45%`） | `motion_start`、`task2_pwm_max_pct=55` |
| 任务二加速 | `LAND_ALIGN(7)`、`DESCEND(8)`、`ON_PLATFORM_5S(9)` 均低速；仅 `PLATFORM_TAKEOFF(10)` 后 | `flight_stage`、`coord_speed_unlocked` |
| 任务二 B | 前轮首次实际运动起算，15 s 内应到 B | `task2_b_within_15s` |
| 整圈 | 从 `motion_start` 起不超过 90 s | `lap_complete` 或 `lap_timeout` |
| 车辆卡滞 | 推进释放后连续 20 s 没有编码器里程增量 | `progress_timeout,NO_ENCODER_PROGRESS_20S` |

出现 `task2_b_late`、`task2_b_deadline_missed`、`lap_timeout` 或 `progress_timeout` 即为失败
证据。`motion_start` 由任一前轮编码器达到 200 cps 记录。20 s 无进展保护只处理卡滞，
不替代 90 s 整圈判据；这两种停车都不是成功完成证据。

### 飞行阶段加速防回归

每次空地联调前后执行下表，不以“收到了无线帧”替代实际速度门验证：

| 注入或观察条件 | 预期小车状态 | 必须记录 |
| --- | --- | --- |
| 错误 `Src/Dst`、TaskType 或 MissionId 的 `0x82` | 拒绝帧，保持 `coord_speed_unlocked=0` | `flight_rx_invalid` 或 `radio_ack_drop_count` 增加 |
| 任务一：B 前、或未见 `DROP_ACTION(6)` 的 `RETURN_HOME(11)` | 保持协同低速 | `radar_b_reached`、`flight_drop_action_seen=0`、`coord_speed_unlocked=0` |
| 任务一：过 B、`DROP_ACTION(6)` 后的 `RETURN_HOME(11)` | 解锁回程速度包络 | `flight_stage=RETURN_HOME`、`coord_speed_unlocked=1`、`coord_speed_unlocked,reason=FLIGHT_STAGE_GATE` |
| 任务二：`LAND_ALIGN(7)` 至 `ON_PLATFORM_5S(9)` | 保持协同低速 | `flight_stage` 与 `coord_speed_unlocked=0` |
| 任务二：`PLATFORM_TAKEOFF(10)` | 解锁回程速度包络 | `flight_stage=PLATFORM_TAKEOFF`、`coord_speed_unlocked=1` |
| 阶段流中断超过 1.5 s，或收到 `ABORT(13)` | 立即重新锁回协同低速，不因无线状态单独停车 | `coord_speed_relocked,reason=FLIGHT_STATE_STALE` 或 `flight_stage=ABORT` |

`MISSION_STATUS(0x82)` 是带 TaskType/MissionId 的阶段权威；`FLIGHT_TELEMETRY(0x02)`
以 ModeCode 持续刷新相同阶段。后者只有当前任务 ACK 已接受、或已收到匹配 `0x82` 后才
能更新速度门，避免无关联的 2 Hz 广播触发加速。

## 现场流程

### 本地无雷达循迹

1. 按 [默认 J-Link SWD 50 kHz 烧录步骤](line_follow_uart_flash.md#j-link-swd-烧录默认)
   烧录 `LineFollowMissionDebug`，确认 JY901 新鲜、灰度位于 A 全黑标记。
2. 关闭 Pi/雷达后按 PG13 或 PG9，应出现 `LOCAL_START_OK` 并继续循迹。
3. 保存灰度、JY901、编码器、失线恢复、A 点停车和 `lap_complete`。
4. 没有 `0x81` ACK、飞行阶段和空中录像时，这只能证明车辆循迹，不能计无人机分。

### PG12 / `0x85` 验证步骤

1. 先以串口 `P` 确认 `pg12_short_press_only=1`、`motors_enabled=0` 和
   `maint_broadcast_left=0`。该状态同时给出维护复位计数与最近结果。
2. 低有效短按 PG12 并等待消抖。日志必须出现
   `maintenance_reset_local_applied,reason=PG12_SHORT_PRESS`；无线侧必须收到三帧相同
   ResetId/Seq/Payload 的 `0x85`，后两帧仅有 `RETRANSMISSION`。
3. 三帧结束后确认 `maint_broadcast_left=0`，再次短按 PG12；新事务必须使用递增的
   ResetId。随后地面站以新的 `0x83` Seq 与新的 CalibrationId 重新写入实际 Delta。
4. V2.3 附录的静止/长按条款不对应当前固件分支；它与 Pi 清除/ACK 缺口一并在 G3
   中记录。不得把本步骤的短按日志标记为该附录条款的验收证据。

### 正式无线协同

1. 按键前完成 Pi 原始位姿、LoRa、飞控、机载 ESP32、地面站和平台预检；确认连续三帧
   原始位姿有效，并逐帧确认 `X=-(X_pi-13 cm)+DeltaX,Y=-Y_pi+DeltaY,yaw=yaw_pi`。当前单向 Pi
   只能做 MCU 本地兼容联调；要主张严格 V2.3 得分，Pi 必须完成 `0x83/0x85` ACK。
2. 只在 `CAR_POSE.Seq mod 5=2` 后的 30--50 ms 窗口发送 `0x83`，必须显式填写现场值：

   ```powershell
   .\scripts\test_line_follow_calibration_link.ps1 -WirelessPort COM12 -DiagPort COM13 -DeltaXCm <现场值> -DeltaYCm <现场值> -CalibrationId <非零ID> -Send
   ```

3. 脚本必须得到 MCU 直接返回的地面 ACK、三帧有序同 ID `CALIBRATED CAR_POSE`，
   且相对校准前出站帧的 X/Y 增量等于输入 Delta；任一失败先修 MCU `0x83`/LoRa
   链路，不等待或排查 Pi ACK。
4. 按 PG13/PG9 后归档 `0x81`、ACK、`0x82/0x02`、B/整圈计时、飞行视频和地面站截图。

## 得分验收矩阵

| 评分项 | 车端代码状态 | 外部节点/物理证据 | 当前结论 |
| --- | --- | --- | --- |
| 任务一 60 分 | 按键、循迹、130 mm/s、速度门已实现 | 起飞、伴飞、25+/-5 g 抛投、D 前完成、返 H | 未验收 |
| 任务二 20 分 | 按键、150 mm/s、B 15 s、再起飞后提速已实现 | D 前落平台、停留 5 s、再起飞返 H | 未验收 |
| 每圈 <=90 s | 12 s 寻线、90 s 保护、计时事件已实现 | 两任务带平台实跑计时 | 未验收 |
| 地面站 15 分 | MCU 提供车端字段 | >=6 in 地图、车/机位置、文字状态、无任务期控制 | 未验收 |
| 平台/物资/场地 | MCU 无法替代 | 尺寸、黑环十字、线宽、物资重量、移除物资 | 未验收 |
| V2.3 互操作 | 帧校验、时隙和车端兼容链已实现；Pi 校准所有权与平台中心几何的严格闭环仍为强制差距 | Pi 原始位姿、空侧、地面站 10 min 负载统计 | 不可声明通过 |

本仓库不包含 Pi 原始位姿源、飞控、机载 ESP32、MaixCam 或地面站源码与部署证据。
Pi 不再是 `0x83/0x85` 的控制或 ACK 节点；其余外部节点的实测证据仍不能由小车 MCU
构建成功替代。

## 证据归档

每次正式尝试至少保存 `car_serial.log`、`ground_station.log`、`flight.log`、连续
`video.mp4` 和 `acceptance.md`。`acceptance.md` 记录镜像 SHA、硬件版本、Delta、场地、
结果和异常。`scripts/analyze_line_follow_frozen_log.ps1` 会输出
`SCORING_TASK2_B_15S` 与 `SCORING_LAP_90S`；旧日志显示 `NA` 时不能倒推为通过。

## 文档状态

| 文件 | 状态 |
| --- | --- |
| 本文 | 当前唯一运行与计分入口 |
| `D题任务一二雷达协同联调.md` | 运行细节补充；冲突时以本文为准 |
| `D题小车端实施基线.md` | 硬件/实现边界补充，不单独声明得分 |
| `line_follow_v23_calibration_integration.md` | `0x83/0x85` 事务细节 |
| `D题_赛题合规差距清单_20260731.md` | 正式计分前必须关闭的协议、几何与外部证据门槛 |
| `radar_pose_line_follow_switch_20260730.md` | 历史迁移证据，不是现场入口 |
| `循迹控制第一阶段计划.md`、`D题_Agent修改提示词_v2.2.md` | 历史资料，不按旧流程执行 |

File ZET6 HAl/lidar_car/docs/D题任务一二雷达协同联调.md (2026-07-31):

# D 题任务一/任务二雷达协同运行补充

更新时间：2026-08-01

> 计分判据和现场入口以 [D题_V23_联调与计分矩阵.md](D题_V23_联调与计分矩阵.md)
> 为准。本页只补充小车运行细节。旧的 PG10 启动、PG9 维护、600 mm/s 首跑流程均已
> 废止；历史日志只作为证据，不作为操作步骤。
> 当前单向 Pi + MCU-local 校准仅可作兼容联调；正式计分前必须逐项关闭
> [D题_赛题合规差距清单_20260731.md](D题_赛题合规差距清单_20260731.md)。
> PG12 的工程标准是停车后短按。权威 V2.3 附录的“静止 12 s + 长按 2--3 s”仅作为
> 外部赛题条款和合规差距记录；当前固件没有对应的切换镜像，不能把两种触发条件合并。

## 按键

| 按键 | 作用 |
| --- | --- |
| PG13 | 任务一（抛投）启动；运行中再次按下为安全停车 |
| PG9 | 任务二（动态起降）启动；运行中再次按下为安全停车 |
| PG12 | 车辆停止后低有效短按，经 50 ms 消抖立即清除本地校准并广播三帧 `MAINTENANCE_RESET (0x85)`；三帧完成后可再次短按，不等待 Pi ACK |
| PG10 | 当前不参与启动、停车或任务控制 |

PG12 不改变 `0x85` 的地址、ResetId、Seq、payload 或三帧重传语义。当前单向 Pi
仍不具备 V2.3 的 Pi 清除/ACK 闭环；外部条款差异与逐项验证见
[D题_V23_联调与计分矩阵.md](D题_V23_联调与计分矩阵.md#pg12-维护复位标准)。

## 雷达坐标与地图方向

以下是 Pi 单向输入的原始地图/安装参考值，不保证等同于本次 `0x83` 后对外发布的
`FIELD_GLOBAL`。X/Y 单位为 cm，yaw 逆时针为正。坐标用于路线显示、B 点里程门和
A 点回程预备，不单独触发停车；本次 Delta、MCU 本地 `CalibrationId` 和校准后的
出站位姿才是现场坐标证据。

| 点位 | X (cm) | Y (cm) | 车体 yaw（约） | 用途 |
| --- | ---: | ---: | ---: | --- |
| A 起点/终点 | 0.0 | 0.0 | 0° | 起跑参考、回程灰度停车前置 |
| B | -151.3 | -8.1 | 0°（实测 -0.7°） | A-B 协同段结束/任务一雷达里程门 |
| C | -165.7 | 150.7 | 180°（实测 -178.1°） | 赛道上边回程方向参考 |
| D | -16.5 | 164.2 | 180°（实测 -179.4°） | D-A 回程段方向参考 |

B 点通常与 A 点航向同向，均接近 `0°`；C、D 点通常与 A/B 相反，均接近 `180°`
（`-180°` 与 `180°` 等价）。由坐标计算的 B-C、C-D 和 D-A 轮廓与
`docs/地图描述.png` 的约 `150 cm x 150 cm` 跑道一致，拐角约为直角。A 点回程若出现
数十厘米坐标残差，以灰度 A 标记为最终停车依据，不在 MCU 端擅自平移坐标。

Pi 到 MCU 的 UART4 为单向 `Pi TX -> MCU RX`，只发送原始位姿；当前不承担
`0x83/0x85` 控制或 ACK。MCU 向 LoRa `CAR_POSE(0x80)` 输出时，X 先减固定
`13 cm`，再镜像 X/Y、后叠加场地校准：
`X_lora=-(X_pi-13 cm)+DeltaX`、`Y_lora=-Y_pi+DeltaY`、`yaw_lora=yaw_pi`。
Pi 输入和本地雷达辅助始终保留原始 `X_pi/Y_pi`；MCU 只在出站帧写入本地
`CALIBRATED` 与 `CalibrationId`。校准前后差值相等不等于镜像正确，需抓 Pi 原始帧
和 LoRa 出站帧逐帧验证这三个公式。

启动键只要求 A 点全黑标记和新鲜 JY901；Pi 未上线、雷达跳变或 MCU 尚未校准时，小车
仍以本地低速进入循迹。连续三帧新鲜的原始 `FIELD_GLOBAL` 位姿与 MCU 本地有效
`CalibrationId` 同时满足后，才生成带该 ID 的 `0x81` 任务请求。V2.3 要求该 ID
与当前出站 `CAR_POSE` 一致，故未校准时不发送伪造的 `0x81`；任务请求失败或无线
ACK 超时只记录状态，不让循迹自动停车；尚未发完的 `0x81` 在安全停车时会取消。

## 速度和阶段门

主运动判据是车端传感器：JY901 提供实时 yaw/yaw-rate 和累计转弯方向，左右编码器
按轮增量累计路径距离；雷达坐标不参与横向控制，只作路线/里程交叉检查、A 点回程预备
和地面站协同显示。

- 任务一离开 A 使用约 `130 mm/s` 协同低速；任务二离开 A 使用约 `150 mm/s` 协同低速。
- 任务一在编码器累计路径达到约 `1550 mm` 后具备 B 进度；雷达连续两帧确认距 A
  至少 `155 cm` 只作坐标辅助。这两个门都在实测 B 点约 `151.5 cm` 之后，不能把
  A-B 伴飞段误判为已过 B。收到当前任务匹配的 `MISSION_STATUS(0x82)` 已经过
  `DROP_ACTION(6)` 且进入 `RETURN_HOME(11)`，才解锁约 `180 mm/s` 的回程速度包络；
  后续 `0x02` 只用于持续状态/丢包恢复。
- 任务二在 `INTERCEPT(3)`、`FOLLOW(4)`、`LAND_ALIGN(7)`、`DESCEND(8)` 和
  `ON_PLATFORM_5S(9)` 都保持 `150 mm/s` 协同低速；仅收到
  `PLATFORM_TAKEOFF(10)` 或之后的非 `ABORT(13)` 阶段才解锁约 `180 mm/s` 包络。
- 加速门在阶段成立时打开；飞行状态超过约 `1.5 s` 未更新或进入 `ABORT(13)` 时回到该任务的协同低速（任务一 `130 mm/s`、任务二 `150 mm/s`），但不会因无线状态单独停车。

## 雷达 A/B 辅助

若起跑门时已有 MCU 本地校准后的有效出站位姿，保存对应原始 A 样本为参考点；运行中只使用
同一 `CalibrationId` 会话内的新鲜原始位姿计算平面距离。起跑后才恢复的 Pi 位姿仍可触发
`0x81` 协同，但不会补抓已经离开的 A 点，避免将中途坐标错误当作 A 参考：

- 编码器累计路径距离达到约 `1550 mm` 时记录 `odometry_b_reached`，作为任务一和
  任务二均可用的 B 进度后备；连续两帧雷达距离 A 达到 `155 cm` 时记录 `radar_b_reached`，作为
  坐标辅助。单帧超过 `40 cm` 的位置跳变被丢弃；
- 回程进入 A 的 `45 cm` 半径时记录 `radar_a_prepare`，进入 `20 cm` 半径时记录
  `radar_a_stop_prepare`；
- 雷达预备不会单独停车。最终停车由灰度 A 标记、JY901 累计偏航和编码器累计路径距离
  共同判定；在已预备的
  A 半径内，雷达只允许短暂的原始全黑样本绕过稳定掩码延迟，避免车辆掠过 A 标记。

雷达位姿过期或校准 ID 改变时，辅助门失效，但循迹和既有 12 s 失线搜索逻辑继续运行。
推进释放后若连续 20 s 没有编码器里程增量，则记录 `progress_timeout` 并安全停车；正常
移动的一整圈仍以 90 s 看门狗为限，不能把 20 s 当作整圈时间上限。

## 无线接收

车端 UART5 按 V2.3 解析 CRC、版本、地址、长度和 ACK 标志：

- `MISSION_STATUS (0x82)`：`src=0x20,dst=0x10,len=12`，载荷为
  `TaskType, Stage, StatusFlags, MissionId, ErrorCode, Reserved, SourceTimeMs`。
  只有 `TaskType/MissionId` 与本次 `0x81 CAR_TASK_REQUEST` 匹配时才改变阶段。
- `FLIGHT_TELEMETRY (0x02)`：`src=0x20,dst=0x10,len=24`，使用载荷中的
  `ModeCode` 作为持续阶段；它没有任务 ID，因此只有当前 `0x81` 已 ACK 后才可作为
  调速依据，匹配的 `0x82` 是更强的会话确认。这样首帧 `0x82` 丢失时，2 Hz 广播仍可
  恢复阶段。
- `0x81` 请求在连续三个车端 `0-25 ms` 时隙各发送一次，同一 `Seq/Payload`，之后恢复
  `CAR_POSE(0x80)`。PG13/PG9 二次急停优先发送三帧 `MISSION_ABORT(0x84)`，等待标准 ACK
  但不影响已经关闭的电机。
- `CALIBRATION_SET(0x83)` 只在小车静止的维护窗口接收：MCU 校验后立即将
  `DeltaX/DeltaY/CalibrationId` 存入本地 RAM，并在下一可用车端时隙直接回
  `0x30 -> 0x40` 地面站 `ACK_ACCEPTED`。Pi 没有回传链路，绝不等待 Pi ACK；
  后续 LoRa `0x80` 才应用这组校准值，内部循迹/雷达原始坐标不变。

阶段编码：`0 IDLE`、`1 PRECHECK`、`2 TAKEOFF`、`3 INTERCEPT`、`4 FOLLOW`、
`5 DROP_ALIGN`、`6 DROP_ACTION`、`7 LAND_ALIGN`、`8 DESCEND`、
`9 ON_PLATFORM_5S`、`10 PLATFORM_TAKEOFF`、`11 RETURN_HOME`、
`12 HOME_LAND`、`13 ABORT`。

## 首轮联调顺序

1. 静止时按 `P` 保存日志；原始 Pi 位姿缺失或 MCU 未校准均不阻止本地起跑。需要协同时，
   先确认连续三帧原始位姿有效且 MCU 本地 `CalibrationId` 非零。
2. 不装载投掷物、桨叶保持安全，按 PG13；确认 `PG13_TASK1_REQUEST` 和
   `LOCAL_START_OK`。Pi 未接入时这一项仍必须能本地循迹。
   原始 Pi 位姿和 MCU 本地校准均就绪时，还应出现三次 `0x81`、对应 ACK 和
   `radar_a_captured`；任一未就绪时应记录 `task_coordination_deferred,RADAR_NOT_READY`，
   但小车必须继续循迹。
3. 观察 `radar_b_reached`；注入或接收匹配 `0x82 Stage=11`，确认只出现一次
   `coord_speed_unlocked`。
4. 回到 A，确认 `radar_a_prepare`/`radar_a_stop_prepare` 和
   `A_MARK_RETURN_RADAR_READY`，检查停车后不再发送任务请求。
5. 复位后用 PG9 重复，发送 `Stage=2`、`7`、`8`、`9` 时仍保持低速，发送
   `Stage=10` 后才提速；记录 `task2_b_within_15s` 或失败事件。
6. 运行中分别再次按 PG13、PG9，确认 `PG13_MANUAL_STOP`/`PG9_MANUAL_STOP`，并确认
   `task_tx_left=0`；PG10 不应产生任务或停车事件。

当前状态：联调固件已完成构建和静态协议检查，待烧录后按本文件的 PG13/PG9、雷达
点位和飞行阶段门进行连续小车/无人机实测；未完成实测的结论不得写成验收通过。

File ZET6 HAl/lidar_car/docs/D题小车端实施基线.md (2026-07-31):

# D 题小车端实施基线

> 2026-07-31 起，任务一/二的现行按键、低速、飞行阶段、计时和得分判据以
> [D题_V23_联调与计分矩阵.md](D题_V23_联调与计分矩阵.md) 为准。本文只保留
> 当前实现、接口边界和可追溯证据；不单独声明赛题通过。
> 正式计分前还必须关闭 [D题_赛题合规差距清单_20260731.md](D题_赛题合规差距清单_20260731.md)
> 的 G1--G7。尤其是单向 Pi 的 MCU-local 校准属于当前兼容路径，不能替代已发布
> V2.3 中 Pi 的平台中心与 ACK 责任。
> PG12 的现行联调默认与附录验收兼容模式是互斥的编译选择：默认短按，不默认附加
> 静止 12 s 或长按门槛；后者只在显式验收镜像中启用。

## 1. 目标与范围

本文件定义 D 题陆空协同系统的小车端运行态。八路灰度、直接接入的 JY901 yaw/yaw-rate
和前轮编码器是车辆本地运动闭环；雷达/树莓派只单向提供原始位姿给 MCU，由 MCU 负责
对外发布的平台中心坐标和校准状态。
小车不负责无人机的起飞、投放、着陆判定或飞控状态机。

通信唯一依据为 `F:\keil5\stm\ZET6 HAl\lidar_car\docs\D题_通用通信与接口规范_v2.3.docx`；
在线帧 Version 仍为 `0x02`。
角色实现约束见 `F:\keil5\stm\docs\D题_Agent修改提示词_v2.2.md`。题目澄清见
[D题 回复.txt](D题%20回复.txt)。

## 1.1 当前雷达路线参考

下表是 Pi 本地原始地图/安装参考；现场 `0x83` 校准后，MCU 才将它映射为对外
`FIELD_GLOBAL`。X/Y 单位为 cm，yaw 逆时针为正。MCU 以起跑时捕获的原始 A 样本
做相对距离辅助，不依赖固定 A=`(0,0)` 启动车辆或停车。

| 点位 | X (cm) | Y (cm) | 航向约定 | 当前用途 |
| --- | ---: | ---: | --- | --- |
| A | 0.0 | 0.0 | 0° | 起跑参考、回程灰度停车前置 |
| B | -151.3 | -8.1 | 0°（实测 -0.7°） | 任务一 B 里程门 |
| C | -165.7 | 150.7 | 180°（实测 -178.1°） | 上边路线参考 |
| D | -16.5 | 164.2 | 180°（实测 -179.4°） | 回程路线参考 |

B 与 A 的车体方向接近 `0°`，C/D 与其相反、接近 `180°`；负角度是同一方向的
`[-180°,180°)` 表示。B-C、C-D、D-A 的实测轮廓与 `docs/地图描述.png` 的约
`150 cm x 150 cm` 跑道相符。雷达只做里程/停车预备和地面站显示；JY901 累计偏航与
编码器累计路径距离才是车辆运动和 A 点判定的主辅助量，最终仍需灰度标记。

## 2. 当前硬件事实

| 子系统 | 已确认事实 | 状态 |
| --- | --- | --- |
| 前轮 TB6612 | PWM `PA2/PA3`，方向 `PE2-PE5`，STBY `PE6` | 当前运动基线 |
| 前轮编码器 | 左 `PA0/PA1 TIM5`，右 `PA6/PA7 TIM3` | 当前反馈基线 |
| 八路灰度循迹 | 地址线 `AD0/AD1/AD2=PC0/PC1/PC2`，数字 `OUT=PG0` | Yahboom 74HC4051 地址扫描接口；X1--X8 已实机验证为 `0x01`--`0x80`，白底基准 `0x00`；X4 左偏 / X4+X5 居中 / X5 右偏的误差符号已验证 |
| 后轮 TB6612 测试 | PWM `PE13/PE14`，方向 `PF1-PF4`，STBY `PB9` | 仅架空四轮测试；与灰度主组无已知引脚冲突 |
| 后轮编码器 | 左 `PB6/PB7`，右 `PC6/PC7` | 目前仅输入轮询，TIM4/TIM8 闭环待完成 |

后轮 STBY 已改接 PB9，灰度主组 `PC0/PC1/PC2 + PG0` 不再与后轮驱动冲突。`FourWheelTb6612Debug` 仍只用于电机带起，因为它不初始化灰度解码、循迹控制和任务状态机；比赛固件需在四轮回归通过后另行验证。

### 位姿与校准物理拓扑

`UART4 PC11 (MCU RX) <- Pi TX` 是当前 Pi 链路的唯一已用方向：Pi 以 10 Hz 发送原始
`CAR_POSE` 或兼容雷达帧，MCU 不向 Pi 发送校准、复位或 ACK。实际校准闭环如下：

`地面站 0x83 -> MCU 本地 RAM(DeltaX/DeltaY/CalibrationId) -> MCU 直接地面 ACK`

`Pi 原始位姿 -> MCU 内部原始状态 -> MCU LoRa 出站校准 CAR_POSE`

因此 Pi ACK 不得作为 `0x83`、PG12 或 `0x85` 的前置条件；原始 Pi/radar 坐标只用于
内部雷达辅助和相对距离，不能被 MCU 本地 Delta 回写或替换。

## 3. 灰度循迹与速度策略

1. 八路灰度映射已验证：白底 `0x00`、居中 X4+X5=`0x18`、左偏 X4=`0x08`、右偏 X5=`0x10`；权重 `-7/-5/-3/-1/+1/+3/+5/+7` 的负值表示黑线在车体左侧。`LineFollowMissionDebug` 由灰度误差、JY901 yaw/yaw-rate 和前轮双 `SpeedLadrc_t` 形成有界差速，后轮同侧开环跟随。后轮编码器未标定，不能称为四轮速度闭环。
2. A 点全黑 `active_mask=0xFF` 只是位置标记。PG13 启动任务一，PG9 启动任务二；运行中再次按对应任务键均进入安全停车。PG10 不初始化、不读取，也不产生启动/停车事件。PG12 用于停车后的短按人工维护复位：50 ms 消抖后 MCU 直接清除本地 Delta、校准标记和 CalibrationId，再广播 `0x85`，不等待 Pi ACK。权威附录的静止/长按时序是外部赛题条款，不对应当前固件分支。
3. 任务一离开 A 以约 `130 mm/s` 协同低速循迹，任务二以约 `150 mm/s` 协同低速循迹。两项任务均可用编码器累计约 `1550 mm` 或雷达连续两帧确认距 A 至少 `155 cm` 作为 B 进度。任务一需见 `DROP_ACTION(6)` 且进入 `RETURN_HOME(11)` 后才允许约 `180 mm/s` 回程速度；任务二在 `INTERCEPT(3)`、`LAND_ALIGN(7)`、`DESCEND(8)`、`ON_PLATFORM_5S(9)` 均不得提速，只能在 `PLATFORM_TAKEOFF(10)` 或之后的非 `ABORT(13)` 阶段提速。
4. 灰度仍是主路径和最终 A 停车依据；JY901 累计偏航加编码器累计路径距离用于防止
   首次经过 A 时误停。雷达使用当前 A/B/C/D 坐标做里程交叉检查、A 点回程预备和地面站
   显示，不单独停车。
5. 失线进入 `LOST_HOLD` 后按最近四帧方向寻线，最多持续 12 s；只有中心传感器捕获并连续 10 个 20 ms 控制周期（约 200 ms）稳定重获后才恢复循迹，超时才安全停车。陀螺仪/编码器短时异常只记录告警；赛题镜像保留 90 s 整圈看门狗，并增加 20 s 无编码器里程增量保护，分别记录 `lap_complete/lap_timeout` 与 `progress_timeout`。
6. 当前转弯差速允许内侧轮有限反向目标（下限 `-800 cps`），并通过每 20 ms 的目标斜率限制平滑变化；急弯优化以差速持续时间为主，不全局放大 LADRC。
7. 无线阶段由 `MISSION_STATUS(0x82)` 绑定任务，再用 `FLIGHT_TELEMETRY(0x02)` 持续补充；`ABORT(13)` 或阶段超过约 1.5 s 未更新时回到协同低速，不因无线状态单独停车。

PG13/PG9 的本地启动只检查 A 点灰度标记和 JY901 新鲜度，不检查雷达、Pi 或
`CalibrationId`。Pi 位姿不可用时记录 `task_coordination_deferred,RADAR_NOT_READY` 并继续
循迹；连续三帧合格的原始位姿与 MCU 本地有效 `CalibrationId` 同时出现后，才补发
不影响推进的 `0x81` 协同请求。

## 4. LoRa 与协同边界

树莓派以 115200 8N1、10 Hz 向 MCU 单向发送原始 `FIELD_GLOBAL` 雷达/SLAM 位姿。
MCU 校验后成为唯一 LoRa 发射者和校准状态所有者：

- 广播 `CAR_POSE`（0x80）10 Hz，坐标单位 cm、yaw 单位 0.1 度。Pi 输入保持原始
  `X_pi/Y_pi/yaw/velocity/SourceTimeMs`；MCU 只在 LoRa 出站计算
  `X_lora = -(X_pi - 13 cm) + DeltaX`、`Y_lora = -Y_pi + DeltaY`，并保持 `yaw_lora=yaw_pi`。
  Pi 不得重复镜像或 Delta；
- MCU 用本地状态覆盖出站 `CALIBRATED/CalibrationId`，并按真实循迹状态写入
  `CAR_RUNNING`。入站 Pi 的校准标记和 ID 不参与内部坐标、协同就绪或对外帧；
- 每个 100 ms 周期仅在 0-25 ms 的车端槽发射；30-55 ms 留给机端回应，55-100 ms 静默；
- PG13/PG9 先发起本地任务；仅当连续三帧原始位姿有效，且 MCU 本地校准状态为同一有效
  `CalibrationId` 后，才以固定任务 ID/序列发送三次 `CAR_TASK_REQUEST(0x81)`；
  Pi/雷达缺席只延后此空地会话，不得阻止电机推进；
- 运行中 PG13/PG9 二次按键立即关闭电机，并优先在连续三个车端时隙发送
  `MISSION_ABORT(0x84)`（`URGENT|ACK_REQUIRED`）；等待 ACK 只用于遥测，不延迟停车。
- 地面 `0x83` 只在车辆静止时接受。MCU 校验后立即更新本地
  `DeltaX/DeltaY/CalibrationId`，并在下一个车端时隙向地面回 `ACK_ACCEPTED`；
  不向 Pi 转发，也不等待 Pi ACK。任务中不得更改 `CalibrationId`；
- 当前物理维护事件为 PG12 低有效短按（50 ms 消抖）且 `CAR_RUNNING=0`；MCU 立即清除
  本地 Delta、`CALIBRATED` 与 CalibrationId，并在连续三个车端时隙广播同一
  ResetId/Seq/Payload 的 LoRa `0x85`。该事件不访问 Pi，后两帧仅携带
  `RETRANSMISSION`；三帧完成后可再次短按并分配新的 ResetId。
- V2.3 附录的静止/长按要求不是当前固件的可选分支；它作为外部赛题条款和 Pi
  清除/ACK 合规缺口一并记录，不能将短按事件标记为该条款的验收结果。
- 任务中小车持续循线，不因 LoRa ACK、遥测延迟或地面站显示而重复启动或停车；仅灰度
  A 标记、20 s 无编码器进展保护、90 s 看门狗、12 s 失线超时和 PG13/PG9 二次按键能结束车辆运动。

LoRa 透明无线模块已于 2026-07-30 完成独立双向台架验证：MCU 采用 `UART5`、115200 8N1，
`PC12=MCU TX -> 无线模块 RX`，`PD2=MCU RX <- 无线模块 TX`。PC 侧远端模块为 COM12，
接收到了逐字节一致的 33 B `CAR_POSE` 官方测试向量；反向发送 23 B `CAL` 官方测试向量后，
MCU 记录了 CRC 有效且字段匹配的 `rx_ok`。当前镜像已启用 10 Hz 位姿转发、车端时隙、
`0x81` 任务重传、`0x82/0x02` 阶段接收和 `0x84` 急停通知；正式现场验收仍需实测。
UART5 不得再同时接 Pi/Nano；Pi 位姿入口固定为 UART4。

当前 `LineFollowMissionDebug` 在没有新鲜 Pi 位姿且小车静止时每 500 ms 发送 `HEARTBEAT(0x03)`；它采用
固定 8 B 载荷 `DeviceStatus(u8) + ErrorCode(u8) + Reserved(u16=0) + UptimeMs(u32, big-endian)`。
一旦 UART4 位姿新鲜，心跳让位给 10 Hz `CAR_POSE(0x80)`；心跳不能替代其 22 B 载荷、车端时隙和校准门禁。

2026-07-30 已由地面站 `raspi@192.168.0.133` 的 `/dev/ttyUSB0` 实测接收：8 B 修复镜像运行后，
`valid` 计数按约 2 Hz 增长，而 CRC、长度和 payload 丢弃计数不再增长。此项仅为维护心跳
台架验收，`car_age=-1` 在未发送 `CAR_POSE` 时属预期结果；证据见
`logs/line_follow_radio_heartbeat_groundstation_20260730.md`。

V2.3 位姿转发代码现已接入同一镜像：UART4 首选 Pi 的原始
`CAR_POSE(src=0x31,dst=0x32,len=22)`，校验 CRC、位置/yaw 有效位、yaw 范围和速度无效
哨兵值后，将其作为 MCU 内部原始状态。Pi 的 `CALIBRATED/CalibrationId` 不被作为校准
权威；MCU 经 UART5 以 `src=0x30,dst=0x10` 每 100 ms 广播时，才按本地状态写入
`X_lora/Y_lora/CALIBRATED/CalibrationId`。为兼容当前物理 Pi 的 14 B `FA...AB` 本地
桥接帧，MCU 也可将其封装为原始预检 `CAR_POSE`；该兼容路径从首个有效旧帧启动 MCU
转发 epoch 作为临时 `SourceTimeMs`。MCU 依据真实循迹状态改写 `CAR_RUNNING` 位；
Pi 数据超过 250 ms 后，车辆跑动中保持 LoRa 静默，静止时退回维护心跳。

2026-07-30 的后续回归中，UART4 RXNE 环形缓冲消除了前台轮询造成的帧失步；MCU 已从 14 B 兼容流向地面站
持续产生新鲜 `CAR_POSE`（`car_age<=0.098s`，约 10 Hz，UART4 原始输入约 20 Hz）。静止原始帧解码为
`X=6 cm,Y=8 cm,yaw=9.6°`，说明 Pi 雷达零位仅有数厘米残差而非 MCU 载荷字节序错误；详见
`logs/car_pose_legacy_bridge_groundstation_20260730.md`。该记录只证明原始位姿显示链路，
不解除 CRC/时隙/任务验收要求。当前实装 Pi 仍仅输出 `FA...AB` 旧桥接帧；在当前单向
硬件构型下，PG12 和 `0x83` 均由 MCU 本地处理，Pi 不保存、也不确认 CalibrationId。
因此当前默认中 PG12 合格短按必须清除 MCU 本地校准并直接三帧广播 `0x85`；若切换
V2.3 附录的静止 12 s + 长按 2--3 s 是外部赛题条款，不取代当前短按触发。

## 5. MaixCam V2.3 协同边界

MaixCam Pro 只与飞控进行 `CAMERA_MODE`、`CAMERA_TARGET`、`CAMERA_ACTION` 和
`CAMERA_ACTION_RESULT` 会话。飞控在接受小车任务后创建 `ModeSeq`，并以
`TaskType + MissionId + ModeSeq` 约束视觉目标和投放动作。小车 MCU 与树莓派：

- 先产生并保持本地 `TaskType/MissionId`；只有 MCU 已取得本地有效
  `CalibrationId` 后才发送 `CAR_TASK_REQUEST`，并在可用时转发经 MCU 校准的 `CAR_POSE`；
- 不生成或解析 `ModeSeq`，不解析相机 TARGET/RESULT，不直接驱动相机或投放舵机；
- 不因相机模式 ACK、视觉目标丢失、投放 RESULT 或遥测延迟停止、重启或改变循迹。

雷达/Pi 位姿可作为无人机外部跟踪输入；这不改变小车以灰度、JY901 和编码器为主的
运动控制权责。MaixCam 仅在飞控已建立有效会话后的末段提供机体系纠偏。

## 6. 运行态与验收

```text
IDLE -> 车上按键选任务 -> 本地灰度/JY901/编码器循迹 -> 完成或安全停止
                         \-> Pi 原始位姿 + MCU 本地校准可用时建立 0x81/0x82/0x02 空地会话
```

最小验收证据：

| 项目 | 必须记录 |
| --- | --- |
| 灰度阵列 | X1--X8 地址扫描位号、`all_white_mask`、地图白黑极性、误差符号、丢线策略；记录每头 `CHANNEL_SWITCH` 日志 |
| A-B | 场地版本、至少多次用时、选定速度和 15 s 余量 |
| 电机 | 指令方向、实际方向、编码器符号、最大安全 PWM |
| LoRa | 帧类型、序列、CRC、位姿年龄、时隙时刻、重发次数 |
| 任务按钮 | 任务类型、任务 ID、单次触发和去重结果 |
| 空地会话边界 | 小车任务 ID 与飞控/相机状态匹配记录；无小车直接相机控制 |

地面站只显示场地、小车、无人机、链路新鲜度和校准/任务状态。任务运行期间不应提供小车启动、停止、调参或代码下发控制。

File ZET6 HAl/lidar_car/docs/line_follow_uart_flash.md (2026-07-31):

# 循迹固件烧录经验与串口恢复方案

当前任务一/二的运行参数和联调顺序以
[D题任务一二雷达协同联调.md](D题任务一二雷达协同联调.md) 为准；本文件只说明烧录恢复。
烧录成功只证明镜像写入和校验完成；正式赛题合规仍以
[D题_赛题合规差距清单_20260731.md](D题_赛题合规差距清单_20260731.md) 为准。

## 默认烧录方式

默认使用 J-Link SWD `50 kHz`，不是 UART ROM Bootloader。2026-08-01 已用该方式
烧录当前 `LineFollowMissionDebug`：J-Link 连上 `STM32F103ZE`、`VTref=3.30 V`，六个
Flash 段全部 `matched`，随后执行复位和 `go`；COM13 `P` 状态确认应用已启动。

`LineFollowMissionDebug` 在本次工作中始终可以正常构建。下列事项仍是诊断结论：

- J-Link 被 USB 识别、且显示 `VTref=3.30 V`，并不代表 SWD 可用。
- `COM13` 是 J-Link CDC UART。它能交换应用诊断信息，但 J-Link 仍可能
  无法初始化目标 DAP。
- 只有目标连接成功且下载/段校验通过，才算烧录成功。VS Code 报
  `localhost:2331` 超时，表示 GDB Server 已在连接目标前退出，不是应用
  固件本身的错误。

工程没有关闭 SWD。`GPIO_Remap_SWJ_JTAGDisable` 仅释放 JTAG 专用引脚，
PA13/PA14 的 SWD 功能仍保留。

## J-Link SWD 烧录（默认）

本次已在 `STM32F103ZE`、`VTref=3.30 V`、SWD `50 kHz` 下完成下载和逐段
`compare-sections` 校验。车辆断电或架空车轮后，在项目根目录的 `cmd.exe` 中执行：

```bat
cd /d "F:\keil5\stm\ZET6 HAl\lidar_car"
powershell -NoProfile -ExecutionPolicy Bypass -File "scripts\jlink_flash.ps1" -Configuration LineFollowMissionDebug -SwdSpeedKhz 50
```

该命令会重新配置和构建 `LineFollowMissionDebug`，写入 `lidar_car.elf`，逐段比对
Flash，并在成功后复位、运行目标。脚本会捕获 GDB 正常的 `Resetting target` 输出，避免
将其误判为烧录失败。输出中的每个段都应显示 `matched`；只有脚本退出码为 `0` 才可开始
实车测试。

## UART ROM Bootloader（仅备用）

诊断串口直接使用 STM32F103 的 USART1：

- PA9：USART1 TX
- PA10：USART1 RX
- 主机端：通常为 `COM13`（`JLink CDC UART Port`）

这正好也是 STM32F103 ROM Bootloader 的 USART1 引脚。因此当 SWD 无法
连接时，可通过串口烧录恢复。

1. 关闭 VS Code 调试和所有占用目标 COM 口的程序。
2. 断开电机电源或架空车轮，避免复位后误动作。
3. 在任意 `cmd.exe` 窗口先切换到项目根目录，再执行：

   ```bat
   cd /d "F:\keil5\stm\ZET6 HAl\lidar_car"
   scripts\flash_line_follow_uart.cmd COM13
   ```

   省略 `COM13` 时默认使用该端口；若 Windows 分配了其他端口，传入实际
   的 `COMx` 即可。
4. 脚本构建完成后会暂停。此时设置 `BOOT0=1`、保持 `BOOT1=0`，然后复位
   或重新上电目标板，按任意键开始下载。
5. 等待 STM32CubeProgrammer 报告下载和校验成功。
6. 设置 `BOOT0=0`，再复位或重新上电，启动新应用。

脚本会配置和构建 `LineFollowMissionDebug`，然后调用本机
STM32CubeProgrammer 2.23.0 CLI 写入并校验 HEX 镜像。脚本不会在写入后
自动复位，因为 `BOOT0=1` 时复位只会再次进入 ROM Bootloader。

## 当前固件烧录后验证项

- PG13 启动任务一，PG9 启动任务二；运行中再次按 PG13 或 PG9 均急停并发送
  `MISSION_ABORT(0x84)`。PG12 在车辆停止后低有效短按，经 50 ms 消抖后 MCU 直接清除
  本地人工校准并在三个连续车端时隙广播 `MAINTENANCE_RESET(0x85)`；三帧完成后可重复
  短按，不等待 Pi ACK。
  PG10 不参与任何任务或急停。
- `LineFollowMissionDebug` 的 PG12 固定为短按，不要求静止 12 s 或长按。烧录后用串口
  `P` 确认 `pg12_short_press_only=1`；`maint_reset_attempts`、`maint_reset_successes`、
  `maint_reset_reject_running`、`maint_reset_reject_busy` 与 `maint_last_result` 可回查刚才
  的按键结果。V2.3 附录的人工作业时序是外部赛题条款，当前固件不提供开关切回该行为，
  也不能替代 Pi 清除/ACK 的正式闭环。
- 任务一离开 A 约 `130 mm/s`，前轮 LADRC 正向 PWM 上限 `45%`；任务二约 `150 mm/s`，
  因 B 点实测约 13 s 而将正向上限提高到 `55%`。这不是固定加 10 PWM，速度达到目标时
  LADRC 仍会自动降占空比；雷达 B/C/D 坐标、B 后速度门和飞行阶段门见当前联调文档。
- Pi -> MCU UART4 是单向原始位姿输入。对外发送的 `CAR_POSE` 仅在 MCU LoRa 出站阶段
  计算 `X_lora=-(X_pi-13 cm)+DeltaX`、`Y_lora=-Y_pi+DeltaY`，保持 `yaw_lora=yaw_pi`，并写本地
  `CALIBRATED/CalibrationId`；原始 Pi/radar 坐标和本地循迹不应用镜像或 Delta。必须
  同时抓 Pi 原始帧与 LoRa 出站帧验证公式，Pi 不得重复镜像。
- 静止时发送 `0x83` 后，应先收到 MCU 直接回给地面站的 `ACK_ACCEPTED`，再观察至少
  三帧同一 CalibrationId 的校准后 `CAR_POSE`；相对校准前出站 X/Y 的增量必须等于
  `DeltaX/DeltaY`。这里不得等待或伪造 Pi ACK。
- PG13/PG9 起步后的空侧联调顺序必须是三帧成功出站、当前 `CalibrationId` 的
  `CALIBRATED 0x80`（本地已经起步时同时带 `CAR_RUNNING`），再是同 `Seq/MissionId/CalibrationId` 的三帧
  `0x81`，最后是空侧 `0x11 ACK`。状态中应看到
  `task_pose_preamble_tx=3`、`task_pose_preamble_required=3` 和
  `radio_uart_err=0`；任一 Pi 位姿失鲜或前导中插入地面 ACK 都会重新计数。
- 中心传感器采用精确 X4+X5 判定；误差到差速的映射连续化，并在任务层限制
  每 20 ms 的基速/差速目标变化，避免进入或退出弯道时跳变。
- 失线后保留最近有效转向方向，最多搜线 12 秒；只有中心传感器捕获并连续 10
  个 20 ms 控制周期（约 200 ms）的居中 `TRACK`/`WIDE` 才恢复正常循迹。
- 未确认回到 A 点时，短暂陀螺/编码器异常和起跑离开 A 超时只记录告警、继续
  循迹；自动停车仅来自确认 A 点、运行满 90 秒或失线搜线超时。当前
  `LineFollowMissionDebug` 禁用 UART `S`，物理急停仍由运行中第二次按 PG13/PG9 完成。
- 若推进释放后连续 `20 s` 没有编码器里程增量，固件记录
  `progress_timeout,NO_ENCODER_PROGRESS_20S` 并安全停车。这是卡滞保护，不缩短正常
  循迹的 90 s 整圈上限。
- 运行中不再同步输出完整 `LF,event=sample` 记录，避免 115200 串口忙等阻塞
  控制周期。RAM 冻结记录仍以 100 ms 保存，停车后发送 `F` 导出分析。
- 紧弯允许内侧轮有限反向目标，当前内侧目标下限为 `-800 cps`；急弯优先调差速
  持续时间，不全局放大 LADRC。

每次实车后导出冻结日志，检查失线保持时长、保持差速、重获计数和反向轮
目标记录，再决定是否继续提高转弯力度。

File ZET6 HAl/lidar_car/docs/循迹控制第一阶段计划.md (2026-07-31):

# 循迹控制第一阶段：控制意图干运行（历史证据，禁止作为当前流程）

> 当前任务一/二已经进入小车/无人机连续联调，运行参数和按键以
> [D题任务一二雷达协同联调.md](D题任务一二雷达协同联调.md) 为准。本文所有
> PG10、旧 PG9、600/400 mm/s、650 ms/45 s 以及下文曾出现的旧 Pi-ACK/维护描述
> 均为历史证据，禁止照此操作；正式计分门槛见
> [D题_赛题合规差距清单_20260731.md](D题_赛题合规差距清单_20260731.md)。
> **PG12 特别说明：** 本页出现的 PG9、PG10、静止 12 s、长按和 Pi-ACK 维护描述均为
> 已废止的历史设计，不是当前联调操作。现行仅为 PG12 停车后短按；V2.3 附录的人工作业
> 时序作为外部条款保留在合规记录中，当前固件没有切换到该行为的开关。

## 历史快照（非现行）

- 历史规划曾写为 PG13 启动任务一、PG9 启动任务二；并假定 PG12 静止满 12 s 后长按
  2 s、向 Pi 请求清除校准后才广播三帧 `0x85`。该流程已废止，不能与当前短按标准混用。
- 任务一离开 A 约 `130 mm/s`，任务二约 `150 mm/s`。JY901 yaw/yaw-rate 与编码器累计路径距离是运动主判据，
  雷达 A/B/C/D 坐标只作里程交叉检查、A 点预备和协同显示。
- 失线搜索最长 `12 s`；A 点停车需要灰度标记、JY901 累计偏航和编码器路径距离。

## 已完成输入证据

- 白底基准：`all_white_mask=0x00`；
- 居中：`X4|X5=0x18`，`err_x100=0`；
- 黑线在车体左：`X4=0x08`，`err_x100=-100`；
- 黑线在车体右：`X5=0x10`，`err_x100=+100`；
- A 点全黑：`0xFF`，只能是路径位置标记，不能启动任务。

证据索引：`logs/gray_tracking_sync_20260730.md`。

## 历史 A 点至 D 点联合观测首跑（2026-07-30，已构建、待落地验证）

`LineFollowMissionDebug` 使用 `LineObserver_t` 联合保存灰度、gyro yaw 与 yaw-rate：

```text
gray mux -> nonlinear gray differential / yaw-rate reference
         -> gyro heading + rate bounded differential correction
         -> left/right target counts/s -> dual front SpeedLadrc
         -> four-wheel signed actuation
```

- 基础速度：**600 mm/s = 3520 counts/s（暂定轮径/每圈计数换算）**。2026-07-28 架空
  600 mm/s 日志约为 598/600 mm/s、PWM 42/42%，但这不是落地循迹通过证据。
- 正常 TRACK/WIDE 弯道保持 **600 mm/s** 基础速度，不再以灰度误差降速；以最大
  `5000 counts/s` 的非线性差速和中心传感器 X4/X5 捕获提高转向权威，外侧误差达到
  `400` 时仅外轮额外增加 10% PWM。离开 A 仍为
  400 mm/s，丢线保持为 360 mm/s；前轮 TB6612/前轮编码器闭环，后轮以同侧 PWM
  **开环跟随**。后轮编码器 TIM4/TIM8 尚未标定，因此不得称为四轮速度闭环。
- 物理前进符号以四驱架空合格镜像为唯一来源：前左/前右/后左/后右为
  `-1/-1/+1/-1`。已收敛到 `bsp_four_wheel_direction.h`，循迹镜像和四驱镜像共同引用；
  这修复了首版循迹镜像仅前轮动作且正逻辑物理倒车的回归。
- 安全启动：仅 **KEY2=PG10（低有效）**；必须位于 A 点全黑 `0xFF` 且 gyro angle 帧新鲜。
  跑动中再次按 PG10 或串口 `S` 都会关闭前、后 TB6612 的 STBY。
- 维护事件（历史，已废止）：**PG9（低有效）**持续按住 2 s，且车辆已连续静止 12 s 后，MCU 不向雷达/Pi
  发送信息，直接在连续三个小车 LoRa 时隙广播同一 `MAINTENANCE_RESET(0x85)`
  ResetId/Seq/Payload。它绝不启动、停车或恢复循迹。它不再是当前地面站联调配置；当前
  当前短按时序以 PG12 及总入口文档为准。
- A 点逻辑：400 mm/s 离开 A，连续 3 个正常线样本后进入 TRACK；一圈后 A 点持续 200 ms
  自动停车。首次尝试到 D 点时，由操作者按 PG10 停车。
- 故障逻辑：从边缘探头进入全白失线时，在 180 ms 内保持该边缘方向的强差速；其余失线使用
  最近三帧差速均值寻线，650 ms 未重获则安全停车并冻结日志。gyro 超过 250 ms 不新鲜、
  编码器不动、或运行超过 45 s 同样安全停车。
- 无线联调：MCU 已接入 UART4 的 Pi 位姿入口。首选 V2.3
  （`src=0x31,dst=0x32,type=0x80,len=22`）；同时兼容已实装的本地 14 B `FA...AB` 雷达帧，
  但后者只能标记为未校准预检显示数据。收到位置/yaw 有效、CRC 正确（在线 Version=0x02）且不超过 250 ms
  的样本时，MCU 改写为 `src=0x30,dst=0x10`，每 `100 ms` 广播一次 `CAR_POSE`；运行位由 MCU
  按实际电机状态设置。Pi 位姿不新鲜时，
  跑动小车保持无线静默；静止维护态才每 `500 ms` 发送固定 8 B 的 `HEARTBEAT(0x03)`。
  该心跳载荷为 `device_status(u8)`、`error_code(u8)`、`reserved(u16=0)`、
  `uptime_ms(u32, big-endian)`，不能启动飞行器。
  在 TaskType、MissionId、CalibrationId 与重试策略就绪前，**不发送**正式
  `0x81 CAR_TASK_REQUEST`。

冻结日志流程：停车后连接 J-Link CDC，执行

```powershell
.\scripts\capture_line_follow_frozen_log.ps1 -PortName COM13
.\scripts\analyze_line_follow_frozen_log.ps1 -Path <上一步输出的日志路径>
```

首轮只判断三件事：灰度差速符号是否令车向正确一侧转、双轮速度能否跟随目标、gyro 的 yaw/
yaw-rate 是否全程新鲜。先不增加速度，也不把雷达位置闭环接入。

## 2026-07-31 转弯实车复验（已记录）

`LineFollowJY901Debug` 的本次完整一圈冻结记录为
`logs/line_follow_frozen_20260731-145320.log`。首次经过 A 点未停车不作为本节结论；
本圈最终以 `A_MARK_RETURN` 停机。

- 内侧轮出现 6 条负目标记录，最低约 `-358 cps`，但 100 ms 冻结采样中的编码器实测速度
  没有跨过零速。因此当前实际策略是强力减速差速转弯，而不是激烈的原地反转，平顺性更好。
  `-800 cps` 的反向上限尚未触及，暂时加大该上限没有实测收益。
- 中心传感器捕获由上一份窗口的 `20/256` 提升至 `41/256`；最大航向误差由 `1797` 限制为
  `600`，避免长弯在 +/-180 度附近造成差速翻转。
- 仍有 `174/256` 条冻结记录处于航向误差限幅，且 `|err_x100| >= 400` 的大误差记录占
  `47.7%`。若实车仍觉得急弯不够利落，应只增加急弯阶段的差速持续时间；不要全局调整
  LADRC，也不要继续扩大反向上限。

## 已归档的干运行边界

`app_line_follow_control.*` 是纯计算模块。`GrayTrackingDebug` 每个采样周期输出：

```text
ctrl_state,target_vx,steer_demand,steer_dir,motor_permit
```

- `TRACK`：候选 `target_vx=400`（沿用已有速度命令的 `V_x` 标度），按
  `steer_demand = clamp(2 * err_x100, -250, +250)` 计算转向意图；
- `LOST_HOLD`：白底/丢线，速度与转向意图均为零；
- `A_MARK_HOLD`：全黑 A 点，速度与转向意图均为零；
- `WIDE_HOLD`：多于 3 个头同时有效，速度与转向意图均为零；
- `motor_permit` 固定为 `0`。本阶段没有包含 `Motor_Init()`、`Motor_Enable()`、
  `Motion_Car_Control()` 或任何 PWM 写入。

负 `steer_demand` 的语义是“应朝车体左侧转向”，正值是“应朝车体右侧转向”。它尚未
绑定到 `Motion_Car_Control(V_x, V_y, V_z)` 的 `V_z` 符号；该符号必须通过单独的低速
转向与编码器回归确定。

## 后续解锁顺序

1. 烧录干运行镜像，重新白底标定；复测中心、左、右、全白和 A 点全黑时的控制意图。
2. 用前 TB6612 + 前编码器进行独立低速前进、左转、右转测试，记录 `V_z` 符号与实际
   车体偏航的对应关系；不得与灰度外环同时首次测试。
3. 仅在第 2 步通过后，把控制意图映射到已验证的编码器速度内环；初始速度使用候选
   `V_x=400`，并设置最大转向、丢线保持和人工急停。
4. 架空确认后才落地直线，再测试缓弯、急弯和 A 点；每档速度记录误差、速度、越线、
   丢线和停车距离。`600` 只能在 `400` 实测通过后复验。

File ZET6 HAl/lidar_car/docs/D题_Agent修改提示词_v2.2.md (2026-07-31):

# D题 Agent 修改提示词 v2.2（历史协议背景，不是当前运行流程）

> 当前实现以 `D题_通用通信与接口规范_v2.3.docx` 和
> [D题任务一二雷达协同联调.md](D题任务一二雷达协同联调.md) 为准。本文仅保留
> 角色边界和协议演进背景；不要按其中旧的按键/任务时序操作现场设备。

本文件记录 V2.2 角色边界的历史背景，不能作为当前通信或现场操作依据。当前唯一通信
规范是 `D题_通用通信与接口规范_v2.3.docx`，当前现场流程见
`D题任务一二雷达协同联调.md`；修改前仍应阅读现有工程并保留既有安全保护。

## 小车端（树莓派 4 + MCU）

树莓派以 115200 8N1、10 Hz 向 MCU 发送 V2.2 `CAR_POSE`。将雷达/SLAM 原点换算到
平台同心圆十字中心，并通过起飞前 `CALIBRATION_SET` 得到 `FIELD_GLOBAL`；前为 `+X`、
左为 `+Y`、yaw 逆时针为正，坐标单位 cm、yaw 单位 0.1 度。MCU 校验后在车端时隙
通过 LoRa 广播 `CAR_POSE`。两个物理按键只发起抛投或动态起降的
`CAR_TASK_REQUEST`，同一序列最多重发三次，ACK 不得重复触发任务或停车。

MCU 仅在小车未运行时转发地面站 `CALIBRATION_SET` 给 Pi；Pi 内存应用成功后才对
地面站确认。校准重启失效，任务中不得修改。任务期间小车必须持续循线一整圈，不依赖
地面站、LoRa ACK 或空中状态改变自身运动。

## MaixCam Pro 相机边界

飞控接受小车任务后创建 `ModeSeq`，再通过 `CAMERA_MODE` 建立相机会话。MaixCam 仅在
会话已建立、`TaskType + MissionId + ModeSeq` 全部匹配时输出 18-byte
`CAMERA_TARGET`，或接受 `CAMERA_ACTION` 并回送 12-byte RESULT；重复
`Seq + RETRANSMISSION` 只回 ACK，不能重复初始化或驱动投放舵机。IDLE 不发送 TARGET。

相机检测 60 x 60 cm 平台上的 30/50 cm 黑色同心圆十字，15-20 Hz 输出机体系
`ErrX/ErrY`，不以画面自主选择任务或投放，不使用 LoRa 或 RTSP 图传。小车端不创建
`ModeSeq`，不解析 TARGET/RESULT，也不直接驱动 MaixCam；雷达/Pi `CAR_POSE` 仍是空地
协同主闭环，视觉只在飞控末段纠偏。

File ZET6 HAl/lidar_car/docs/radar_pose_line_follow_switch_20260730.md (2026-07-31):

# Radar pose auxiliary interface — 2026-07-30 (historical migration evidence)

> 当前任务一/二联调不使用本页的“雷达替代循迹”结论。JY901 yaw/yaw-rate 与编码器
> 路径距离是车辆运动主判据；雷达坐标仅用于协同位姿、B/A 交叉检查和地面站显示。
> 当前按键、阶段、计时和得分判据见
> [D题_V23_联调与计分矩阵.md](D题_V23_联调与计分矩阵.md)。本页是迁移历史，不是现场入口。

## Recorded link information

- Radar-car Pi: `ubuntu@192.168.0.131`; local key:
  `~/.ssh/lidar_humble_ed25519`.
- `/dev/mcu_usb -> /dev/ttyUSB0`, CP2102, is owned by the Pi pose bridge.
- The bridge process is `pose_bridge_minimal_humble.py`, configured for 115200
  baud, 20 Hz output and serial enable.
- At the inspection time, RF2O reported `Waiting for laser_scans...`; the
  bridge therefore reported `valid=0, reason=odom_stale`. A stale packet must
  never be used for motion.

## Historical STM32 migration path

```text
Pi radar/SLAM pose (X/Y/yaw) --UART4--> legacy 14-byte compatibility parser
```

- UART4 frame: `FA | sx xxx | sy yyy | syaw yyy | AB`, 14 bytes.
- `sx/sy/syaw`: `00=positive`, `01=negative`; X/Y unit cm; yaw unit 0.1°.
- Parser validity requires framing, sign/range checks, UART-error-free receive,
  and age no more than 250 ms.

## Current field controller selection

The historical `LineFollowJY901Debug` target does **not** initialize this
UART4 path for steering. The active `LineFollowMissionDebug` target does
initialize UART4 for the Pi V2.3 pose and calibration-control link, but it
uses that data only for cooperation, coordinates, and A/B cross-checks. It
still uses the verified direct JY901 link on remapped USART2
(`PD5=MCU TX -> JY901 RX`, `PD6=MCU RX <- JY901 TX`, 9600 8N1) for yaw and
yaw-rate steering. Gray X1--X8 remains the primary line-error source and front
encoder LADRC remains the speed inner loop. Do not combine radar yaw and JY901
yaw until an explicit source-selection/fusion test has acceptance evidence.

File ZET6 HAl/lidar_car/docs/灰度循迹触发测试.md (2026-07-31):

# 八路灰度循迹：74HC4051 地址扫描测试

> 本页仅用于灰度模块接线、极性和逐头标定，不是任务一/二的烧录或运行入口。
> 正式小车镜像为 `LineFollowMissionDebug`；当前本地循迹与空地协同边界见
> [D题_V23_联调与计分矩阵.md](D题_V23_联调与计分矩阵.md)。

本车使用 Yahboom `YB-MVX05-V1.0` 八路灰度模块。模块并非三路 ADC 加一路
数字输入，而是内置数据选择器：MCU 用三根地址线选中 X1--X8 中的一头，再从
一根 `OUT` 读取该头的**数字**状态。该模块的 `AD0/AD1/AD2 + OUT` 工作方式和
真值表可见 [Yahboom 8-channel module reference](https://rcdrone.top/products/yahboom-grayscale-line-tracking-sensor)。

蓝光版可用于白底黑线地图；安装高度先保持在产品给出的 `16--24 mm` 范围内，再按
本文件标定实际车体的读数极性。

## 当前引脚与真值表

| 模块针脚 | STM32 引脚 | 方向 | 作用 |
| --- | --- | --- | --- |
| `AD0` | `PC0` | GPIO 输出 | 通道地址 bit0 |
| `AD1` | `PC1` | GPIO 输出 | 通道地址 bit1 |
| `AD2` | `PC2` | GPIO 输出 | 通道地址 bit2 |
| `OUT` | `PG0` | GPIO 输入 | 所选通道的数字输出 |
| `5V/GND` | 5 V / 共地 | 电源 | 不能遗漏共地 |

`PC0/PC1/PC2` 以前被错误地按 ADC 输入读取；旧日志中的 `adc0/adc1/adc2` 是悬空
地址脚读数，不是八头的反射值，不能继续作为循迹映射证据。

| `AD2 AD1 AD0` | 所选物理头 | `raw_mask` 位 |
| --- | --- | --- |
| `000` | X1 | bit0 (`0x01`) |
| `001` | X2 | bit1 (`0x02`) |
| `010` | X3 | bit2 (`0x04`) |
| `011` | X4 | bit3 (`0x08`) |
| `100` | X5 | bit4 (`0x10`) |
| `101` | X6 | bit5 (`0x20`) |
| `110` | X7 | bit6 (`0x40`) |
| `111` | X8 | bit7 (`0x80`) |

`GrayTrackingDebug` 在每个 20 ms 采样周期内依次选择八个地址，并输出：

- `raw_mask`：八个头的原始数字值，bit0--bit7 对应 X1--X8；
- `active_mask`：当前 `raw_mask XOR all_white_mask`，因此不依赖模块的高/低极性；
- `stable_mask`：`active_mask` 连续一致 3 次后的去抖结果。

## 烧录与逐头测试

本固件先执行 `MotorSafe_InitOff()`；前后 TB6612 均关闭。

```powershell
.\scripts\jlink_flash_gray_tracking.ps1
```

1. 让 **所有八个探头位于白底**，在同一日志中发送 `W` 建立白底掩码。
2. 对 X1--X8 逐头执行：该头白底采样，再只将该头移到真实黑线采样。
3. `MUX_MAP_LOCAL_WHITE_BLACK` 中只有本头的 `SELECTED_BIT` 从白底 `0` 到黑线
   `1`，且两段均稳定时，才记录 `CHANNEL_SWITCH`。

示例（先建立白底，再测试 X1；所有命令均由上位机执行）：

```powershell
$log = '.\logs\gray_mux_x1_<timestamp>.log'
.\scripts\capture_gray_tracking.ps1 -PortName COM13 -Command W -Seconds 3 -OutputPath $log
.\scripts\capture_gray_head_phase.ps1 -PortName COM13 -Position 1 -Phase white -OutputPath $log
.\scripts\capture_gray_head_phase.ps1 -PortName COM13 -Position 1 -Phase black -OutputPath $log
.\scripts\analyze_gray_mux_log.ps1 -Path $log
```

对 X2--X8 继续使用同一白底基准或每次重新建立 `W` 基准；重建基准时必须保证八头
全部在白底。`1`--`8` 串口命令仅为人工位置标记，不参与模块选通。

## 验收与边界

- 只有完成 X1--X8 的 `CHANNEL_SWITCH` 映射后，才允许生成加权横向误差和接入循迹 PID。
- 若所有 `raw_mask` 永远相同，优先检查 `AD0/AD1/AD2` 线序、5 V 供电、共地和 3.3 V
  地址高电平是否被模块可靠识别；不要退回 ADC 阈值方案。
- `OUT` 是 5 V 供电模块的数字输出；现有 `PG0` 已被实机读取，但任何重接线前仍需
  确认没有把 5 V 送入不耐压的 MCU 引脚。
- 旧 `gray_mapping_20260730-*.log` 和 10:15--10:30 的逐头 ADC 记录只作“错误驱动
  已定位”的归档，不作为当前八路传感器有效性结论。

## 2026-07-30 实机验收结果

证据日志：`logs/gray_mux_retest_20260730-104601.log`。先让八头同时处于白底并发送
`W`，得到 `all_white_mask=0x00`；随后逐头移至黑线。X1--X8 均获得
`CHANNEL_SWITCH`，且黑线阶段只有对应位稳定置位：

| 探头 | 白底 `active_mask` | 黑线对应位 | 结论 |
| --- | --- | --- | --- |
| X1 | `0x00` | `0x01` | 已验证 |
| X2 | `0x00` | `0x02` | 已验证 |
| X3 | `0x00` | `0x04` | 已验证；复测未见 X4 串扰 |
| X4 | `0x00` | `0x08` | 已验证 |
| X5 | `0x00` | `0x10` | 已验证 |
| X6 | `0x00` | `0x20` | 已验证 |
| X7 | `0x00` | `0x40` | 已验证 |
| X8 | `0x00` | `0x80` | 已验证 |

该结果只确认“模块地址、MCU 引脚、通道位号、白/黑可分”均正确；尚未确认模块在车体
朝向下的左/右误差正负，且尚未允许电机参与循迹。

## A 点全黑起点区域（2026-07-30）

用户将整组探头置于 A 点起始的全黑区域后，采集
`logs/gray_mux_all_black_A_20260730-110324.log`。`K` 黑色快照和后续连续样本均为
`raw_mask=0xFF`、`active_mask=0xFF`、`stable_mask=0xFF`，因此全黑区域与全白背景
`0x00` 可稳定区分。

这只是赛道的视觉标记证据：若后续任务状态机需要识别 A 点，可使用“稳定全黑”作为
路径位置条件；**不能**以它替代车上实体按键的任务启动条件。当前 `GrayTrackingDebug`
只记录该状态，仍不驱动电机。

## 正常黑线居中零点（2026-07-30）

用户将正常黑线置于阵列居中位置（X4、X5 同时触发）后，采集
`logs/gray_mux_center_x4_x5_20260730-110625.log`。连续 24 条有效采样均为
`raw_mask=active_mask=stable_mask=0x18`，即 bit3 与 bit4 同时置位。

因此，当前地图与安装高度下的循迹零点定义为 `center_mask=0x18`。后续加权误差的
数值零点由 X4/X5 的对称权重产生。

## 车体左/右误差符号（2026-07-30）

在车头朝向不变的条件下，正常黑线向车体左侧偏移时，连续 23 条样本稳定为仅 X4：
`0x08`（日志 `logs/gray_mux_vehicle_left_x4_20260730-111544.log`）；向车体右侧偏移
时，连续 23 条样本稳定为仅 X5：`0x10`
（日志 `logs/gray_mux_vehicle_right_x5_20260730-111651.log`）。

因此固件的静态诊断权重固定为 X1--X8：`-7/-5/-3/-1/+1/+3/+5/+7`；
`err_x100 < 0` 表示黑线在车体左侧，`0` 表示 X4+X5 居中，`> 0` 表示黑线在车体右侧。
本阶段仅打印 `line_class`、`line_side`、`active_count`、`err_x100`；不输出 PWM 或
方向控制。`0xFF` 明确标记为 `A_MARK`，`0x00` 标记为 `LOST`，均不参与横向误差计算。

每次烧录或复位都会清除 RAM 内的白底基准。新镜像已在 2026-07-30 11:19 烧录验证，
烧录后必须先执行一次“八头全白 + `W`”，再采集上述误差字段；否则日志显示 `UNCAL`，
属于预期安全状态。

### 误差诊断回归结果

重新白底标定后，当前镜像的实机输出已回归：X4+X5 居中为 `LINE/CENTER/0`，仅 X4
（黑线在车体左）为 `LINE/VEH_LEFT/-100`，仅 X5（黑线在车体右）为
`LINE/VEH_RIGHT/+100`。对应日志见 `gray_error_diag_center_20260730-112143.log`、
`gray_error_diag_vehicle_left_x4_20260730-112215.log` 和
`gray_error_diag_vehicle_right_x5_20260730-112247.log`。因此现可记录可靠的横向误差；
尚不可直接使能循迹电机输出。

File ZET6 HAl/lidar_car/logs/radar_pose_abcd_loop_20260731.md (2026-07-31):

# Radar Pose A/B/C/D Loop Record - 2026-07-31

## Acquisition context

- Pi stack: `phase8_slam_rf2o_bridge_serial.launch.py`, restarted while the
  vehicle was stationary at A.
- Coordinate frame: the pose bridge locked its local origin at A from raw
  `(0.09 cm, 0.12 cm, 0.12 deg)` and emitted the first valid local pose as
  `(0.0 cm, 0.0 cm, 0.0 deg)`.
- Source log: `/home/ubuntu/lidar_logs/phase8_slam_bridge_serial_20260731_161110.log`.
- Units: X/Y are centimetres; yaw is degrees in `[-180, 180)`.
- Only stationary `bridge_out valid=1` samples were used below. Reported point
  values are the centre of each captured stable window.

## Point coordinates

| Point | X (cm) | Y (cm) | Yaw (deg) | Valid samples | Pose age (ms) | Window stability |
| --- | ---: | ---: | ---: | ---: | ---: | --- |
| A start / origin | 0.0 | 0.0 | 0.0 | first valid frame | 118 | Bridge origin locked at A |
| B | -151.3 | -8.1 | -0.7 | 12 | 19-174 | X 0.4 cm, Y 0.2 cm, yaw 0.1 deg |
| C | -165.7 | 150.7 | -178.1 | 12 | 19-169 | X 0.3 cm, Y 0.3 cm, yaw 0.1 deg |
| D | -16.5 | 164.2 | -179.4 | 12 | 19-171 | X 0.1 cm, Y 0.2 cm, yaw 0.1 deg |

`-178.1 deg` and `-179.4 deg` are equivalent to `181.9 deg` and `180.6 deg`
when expressed in a `[0, 360)` convention.

## Map relation

The endpoint geometry is consistent with the approximately 150 cm by 150 cm
course shown in `docs/地图描述.png`:

| Chord | Measured length (cm) |
| --- | ---: |
| A start -> B | 151.5 |
| B -> C | 159.5 |
| C -> D | 149.8 |
| D -> A start | 165.0 |

The corresponding waypoint turns at B, C, and D are approximately 88 deg,
90 deg, and 89 deg. B/C/D are retained as usable route-reference coordinates
for this origin frame.

## Heading convention for current integration

- A and B are the same straight-side heading and should be treated as approximately
  `0 deg` (the measured B value `-0.7 deg` is within the stationary tolerance).
- C and D are the opposite straight-side heading and should be treated as approximately
  `180 deg`; the measured `-178.1 deg` and `-179.4 deg` are the wrapped representation
  of that direction.
- These headings and coordinates agree with the road outline in `docs/地图描述.png` and
  are now the active car/air integration reference. They are not a replacement for the
  gray A marker when deciding the final stop.

## Return-A observation

The returning A measurement is recorded separately and does not overwrite the
start-origin coordinate:

| Item | Value |
| --- | ---: |
| Stable return-A centre | X = 5.8 cm, Y = 40.2 cm, yaw = -11.8 deg |
| Return samples | 18 valid samples, age 18-170 ms |
| Position closure relative to A start | approximately 40.6 cm |
| Yaw closure relative to A start | approximately -11.8 deg |

This records the observed return-A offset for later investigation while keeping
the A/B/C/D reference coordinates above unchanged.

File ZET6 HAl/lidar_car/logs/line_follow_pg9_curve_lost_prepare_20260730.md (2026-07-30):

# 2026-07-30 PG9 地面站维护事件与循迹优化准备记录

## 实现范围

- `PG9` 配置为低有效物理键；连续按住 `2 s`，且车端状态已连续静止 `12 s` 后才有效。
- 有效按下不向 UART4 雷达/Pi 写入任何信息；MCU 将在连续三个小车发送时隙直接广播
  `MAINTENANCE_RESET (0x85)` 到 LoRa 广播地址。
- 三帧使用同一非零 `ResetId`、同一 `Seq` 与相同 8 B payload；后两帧仅增加
  `RETRANSMISSION` 标志。按键不会启动、停止或恢复循迹。
- 正常 TRACK/WIDE 弯道保留 `600 mm/s` 基础速度；灰度/航向差速上限提高到 `5000 cps`，
  X4/X5 保持零点并增强单侧中心传感器捕获；外侧误差达到 `400` 时仅外轮额外增加 `10% PWM`。
- 边缘传感器后的全白失线，在 `180 ms` 内延续该边缘方向；否则使用最近三帧差速均值，
  `650 ms` 内未重获仍安全停车。

## 协议边界

`D题_通用通信与接口规范_v2.3.docx` C.3 的正式校准清除流程要求 Pi 清除状态并 ACK。
本次按使用者决定为不向 Pi 发数据的地面站联调配置，故不清除 Pi 中任何可能残留的
`CalibrationId` 或偏置。仅可在 Pi 已未校准时测试地面站接收；若 Pi 开始持久保存校准，
必须恢复完整 Pi 清除/ACK 事务后才可作为正式维护复位。

## 静态验收

| 项目 | 结果 |
| --- | --- |
| `LineFollowJY901Debug` 构建 | PASS；最新 FLASH `33276 B`，RAM `13144 B` |
| PG9 源码无 `RobotUart_ServoWriteBuffer` | PASS |
| 2 s / 12 s / 三帧与重发标志检查 | PASS |
| V2.3 C.6 固定向量 CRC | PASS，`AA 55 02 85 30 10 52 00 08 00 01 01 00 00 00 04 D2 9C B2` |
| `git diff --check` | PASS |

## 烧录状态与当前实车证据

初次脚本烧录在 GDB Server 尚未完全就绪时连接 `localhost:2331`，造成 `.data MIS-MATCHED`；
这不是目标 Flash 校验失败。改为等待服务器完成目标连接后，`LineFollowJY901Debug` 已完成下载，
`.isr_vector/.text/.rodata/.init_array/.fini_array/.data` 均 `matched`，并执行 reset/go。

随后从 COM13 导出的 `line_follow_frozen_20260730-232647.log` 是 5000 cps 版本的完整一圈：

- 193 条样本、22.443 s 窗口，终点 `A_RETURN_AFTER_2_ARCS`，gyro 全程新鲜；
- 边缘误差 `|gray_err_x100|>=400` 为 120/193（62.2%），中心捕获仅 32 条；
- 外侧误差达到 600/700 时实际进入 `total_diff=-5000 cps`，目标约为左 `4200 cps`、右
  `1020 cps`，外轮命令达到 `55%`；因此弯道风险不是“边缘最大差速不够大”，而是纠偏开始
  得太晚，导致长期依赖边缘头；
- 原日志的控制曲线并不连续：`|err|=100/200/300` 的平均目标轮差仅约
  `628/1387/1680 cps`，随后才跳入边缘饱和。最新镜像改为单调的灰度主导下限：部分 X4/X5
  为 `1800 cps`、`|err|>=200` 为 `2600 cps`、`|err|>=300` 为 `3400 cps`；受目标上限后
  对应目标轮差约为 `1580/1980/2380 cps`。中心阶段外轮仍额外增加 `5%` 前馈；边缘
  `5000 cps / 55%` 与失线保护保留。

### 单调差速包络实车复测

`line_follow_frozen_20260730_smooth_envelope.log` 已完成完整一圈，终点仍为
`A_RETURN_AFTER_2_ARCS`：

| 指标 | 5000 cps 基线 | 单调包络 | 变化 |
| --- | ---: | ---: | ---: |
| 样本 / 窗口 | 193 / 22.443 s | 200 / 23.245 s | 同级完整圈 |
| 边缘样本 `|err|>=400` | 120（62.2%） | 108（54.0%） | **-8.2 个百分点** |
| 最大灰度误差 | 700 | 500 | 改善 |
| 100/200/300 误差目标轮差 | 628/1387/1680 cps | 1580/1980/2429 cps | 单调、提前 |
| gyro 新鲜度 | 全程新鲜 | 全程新鲜 | 保持 |

结论：提前的单调差速确实降低了边缘依赖，且未丢线、未破坏终点停车；但 54.0% 仍偏高。
进一步检查本次日志发现，多段弯道的 `heading_err` 接近 `+/-1783`（角度环跨越 wrap 边界），
并使 `gyro_diff` 多次钳在 `+/-300 cps`。这会让上一个弯道的航向参考残留到下一直线。

### 航向中心泄放反例与回退

`line_follow_frozen_20260730_heading_recenter.log` 的终点为 `LINE_LOST_TIMEOUT`，故该版
**不能作为有效优化保留**。虽然边缘占比为 53.6%，但在最后弯道重新达到 `err=700`，出现
`X8 -> all-white`，随后 650 ms 内未恢复。中心泄放仅减少了局部直线航向残余，未降低关键
弯道的最大误差，且没有提高完整圈可靠性，因此已回退该修改。

失败序列还暴露了一个直接控制退化：失线前 X8 为 `-5000 cps / 外轮55%`，进入
`LOST_HOLD` 后却降为 `-3600 cps / 外轮45%`，使寻线动作反而变弱。历史 `33348 B` 镜像曾
烧录并作如下针对性尝试（后续失败，当前不保留）：

- 撤销未验证的航向中心泄放，恢复上一版完整一圈的航向控制；
- `LOST_HOLD` 定向寻线差速由 `3600` 提至 `4400 cps`；
- `LOST_HOLD` 外轮同样允许 `+10%`，上限 `55%`，不再在 X8 后削弱转向。

### 失线增强后的状态抖动

`line_follow_frozen_20260730_lost_recovery_attempt.log` 仍以 `LINE_LOST_TIMEOUT` 停止，
且实车观察到“卡顿”。日志表明电机不是意外断电，而是状态机在边缘抖动：

`X8(err=700) -> all-white(LOST_HOLD) -> X8(TRACK) -> all-white(LOST_HOLD)`。

旧代码一出现单帧 `TRACK` 就退出 `LOST_HOLD`，使目标在 `4200/500` 与 `4200/1020 cps`
之间反复切换，造成机械卡顿，最终仍未把线拉回内侧。历史 `33440 B` 镜像曾尝试：

- 仍保留失线 `4400 cps / 外轮55%` 的定向寻线；
- 只有连续 **3** 个内侧 `X3..X6`（`|err|<=300`）TRACK 样本才退出 `LOST_HOLD`；
- 单帧 X1/X8 重现不再使状态来回切换，避免卡顿。

该状态门限版本未跑完，故作为反例保留，不是当前控制基线。

### 日志计算后的基线回退

比较现有完整/失败记录后，不能把“边缘占比更低但未完成”的结果当作优化：

| 镜像 / 日志 | 完成 | 边缘占比 | 最大误差 | 结论 |
| --- | --- | ---: | ---: | --- |
| `232647` 5000 cps | 是 | 62.2% | 700 | 可跑基线 |
| `smooth_envelope` | 是 | **54.0%** | **500** | 当前最佳完整圈 |
| `heading_recenter` | 否 | 53.6% | 700 | 不保留 |
| `lost_recovery_attempt` | 否 | 43.5% | 700 | 不保留 |

因此先回退到唯一“完整圈且边缘占比最低”的 `smooth_envelope` 参数：
`1800/2600/3400 cps` 的灰度单调差速包络、边缘 `5000 cps/55%`、原始失线恢复状态机。
后续弯道只允许基于多圈重复日志的完成率、边缘占比、最大误差、轮速跟踪误差进行调整，
不再凭单次视觉感受叠加失线状态机变更。

回退后的 `line_follow_frozen_20260730_known_good_retest.log` 仍在同一弯道失线。随后试验的
`33384 B` 硬弯覆盖曾在 `|err|>=400/500` 时强制 `4200/800`、`4200/350 cps` 轮速目标，
但实车仍在弯道失线；它把外轮推到 `55%`、把内轮压到极低速度，未提高可靠性，**不再保留**。

### 2026-07-31：恢复 Git 弯道基线，只保留失线方向记忆

按实车结论“轮差提高到一定程度已是最优”，曲线主控制恢复到已提交的
`610fa9c feat: complete one-lap JY901 line-follow checkpoint`：

| 项目 | 当前值 | 作用 |
| --- | ---: | --- |
| 灰度差速上限 / 总差速上限 | `2200 cps` | 不再使用 `5000 cps` 大轮差 |
| 轮差增益（\|err\| ≤100 / ≤300 / ≤500 / >500） | `1 / 3 / 4 / 5` | Git 基线非线性权重 |
| 弯道公共速度（轻 / 硬 / 紧） | `500 / 420 / 280 mm/s` | 在硬弯降低公共速度，保留可用转向余量 |
| `LOST_HOLD` 定向轮差 | `2200 cps` | 与 Git 基线一致 |

唯一保留的微调是**不改变正常 TRACK 弯道参数**的失线方向记忆：X2/X3 或 X6/X7 以上边缘
样本后的 `180 ms` 内若变全白，沿最近三帧的转向侧，以同样的 `2200 cps` 寻线；不再抬外轮、
不再压低内轮、也不增加新的状态门限。这样可单独验证“恢复 Git 弯道数据”是否比大差速覆盖稳定。

本版本已构建并经 J-Link 完整校验烧录：`LineFollowJY901Debug`，FLASH `32952 B`、RAM
`13144 B`；`.isr_vector/.text/.rodata/.data` 全段 `matched`，随后 reset/run。当前诊断口
`COM13` 在主机侧未能打开，因此本条只记录烧录校验，不把实车结果误写为已验收。

### 2026-07-31：恢复 `b81e6c5` 弯道控制基线

按确认的历史点 `b81e6c5 feat: relay radar pose to ground station` 恢复全部弯道控制：灰度/总差速
和失线定向轮差均为 `2200 cps`；灰度增益为 `1/3/4/5`，yaw 增益为 `3/4/5/5`；弯道公共速度保持
`500/420/280 mm/s`。移除后续的中心捕获、大差速、三帧失线历史和边缘外轮前馈。A 点弧线终点判定
仍来自该版本的父提交，保持不变。

无线链路不是弯道控制的一部分：当前 LoRa `CAR_POSE` 的 X/Y 取反继续保留，yaw 与速度不变。
本恢复候选尚未产生新的实车验收日志。

该基线已改用 STM32CubeProgrammer 的 J-Link 接口完成写入：擦除扇区 `0..15` 后下载
`lidar_car.hex`，工具报告 `Download verified successfully` 并 reset。随后 COM13 状态回读为
`IDLE/BOOT`、`stable_mask=255`（A 点全黑）、`gyro_fresh=1`、`motors_enabled=0`；这证明烧录
镜像已运行且满足 PG10 启动前置条件，但尚不代表已完成实车一圈验收。

无线坐标变换继续保留：LoRa `CAR_POSE` 转发 `X/Y` 取反，yaw 与速度字段不变。
静态向量 `X=6,Y=8,yaw=9.6°` 编码为 `X=FF FF FF FA`、`Y=FF FF FF F8`、yaw `00 60`。

## 旧固件实车冻结证据（23:18）

已从 COM13 导出 `line_follow_frozen_20260730-231838.log`。状态回读的终点为
`LINE_LOST_TIMEOUT`，说明实际运行的是旧镜像（状态行尚无 PG9 字段），不是本记录所述
的新构建。

- 169 条、19.623 s 窗口，158 条 TRACK；gyro 全程新鲜，无 UART4 丢帧；
- 98/169（58.0%）样本 `|gray_err_x100|>=400`，仅 21 条中心捕获；
- 失线前的序列为右侧 `X7=0x40 -> X7|X8=0xC0 -> X8=0x80`，误差从 `+500` 到 `+700`；
  旧代码差速已饱和在 `-2200 cps`，目标约为左 `2742 cps`、右 `542 cps`，仍进入全白；
- 首个失线能短暂重获，第二个失线持续超过 `650 ms`，最终按保护停车。

结论：灰度符号与 gyro 新鲜度并非本次直接故障。`5000 cps/55%` 大差速虽然曾跑完一圈，
但近期重复实测未提高弯道可靠性；因此回到已提交的一圈检查点，只在失线时保留定向寻线的最小改动。

## 下一步最小动作

1. 让小车停在 A 点全黑起点，PG10 启动；重点观察 B-C 与最容易触发边缘头的弯道。危险时再次按 PG10 安全停车。
2. 一圈后从 COM13 发送 `F` 导出冻结日志；先验收 `A_RETURN_AFTER_2_ARCS`、不出现 `LINE_LOST_TIMEOUT`，再比较边缘占比和轮速跟踪误差。若发生全白，只记录触发前后的 20 ms 样本；下一次只允许调一个 Git 基线参数。
3. 停车超过 12 s，长按 PG9 约 2 s；地面站应收到三帧 `0x85`。记录相同 ResetId/Seq/payload、后两帧重发标志。

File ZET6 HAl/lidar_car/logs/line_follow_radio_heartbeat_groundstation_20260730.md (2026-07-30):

# 2026-07-30 地面站 HEARTBEAT 空口验收

- **模式**：`COMPETITION_LINE_FOLLOW` 的维护无线测试镜像；车辆未由本项测试驱动电机。
- **小车镜像**：`LineFollowJY901Debug`，构建后 `FLASH=26252 B`，J-Link 分段比较均为 `matched`。
- **小车发送**：UART5（PC12 MCU TX -> 无线模块 RX，115200 8N1），从上电起每 500 ms 发送
  V2.2 `HEARTBEAT (0x03)`，`src=0x30`、`dst=0x10`、无 ACK。
- **固定 Payload（8 B）**：`DeviceStatus(u8)`、`ErrorCode(u8)`、`Reserved(u16=0)`、
  `UptimeMs(u32, big-endian)`；整帧为 19 B，CRC16/CCITT-FALSE 覆盖 Version 至 Payload。

## 接收端证据

地面站为 `raspi@192.168.0.133`，接收进程
`/home/raspi/.local/bin/ground_station_ui.py` 持有 `/dev/ttyUSB0`，本地串口配置为 115200。
其 `decode_heartbeat()` 要求长度为 8 B、`Reserved=0`，与本次发送格式一致。

修复前旧空载帧在 `20:59:34` 被明确丢弃：

```text
HEARTBEAT payload must be 8 bytes, got 0
```

修复镜像运行后的地面站统计如下；`valid` 持续增加，而 `crc`、`length` 和 `payload` 丢弃计数保持不变：

```text
21:03:10  valid=2101 crc=0 length=0 payload=1689 dropped=332
21:03:52  valid=2185 crc=0 length=0 payload=1689 dropped=332
```

42 秒内增加 84 个合法帧，即约 2 Hz；没有新的 `HEARTBEAT payload must be 8 bytes` 告警。

## 结论与边界

`HEARTBEAT` 的透明无线收发、帧长、保留字段和 CRC 已通过地面站实测。`car_age=-1` 仍为预期：
当前维护帧不是 22 B 的 `CAR_POSE (0x80)`，不携带平台中心位置、校准 ID 或位姿有效标志。
不得将本记录作为 10 Hz 位姿、LoRa 时隙、任务请求或陆空协同任务验收。

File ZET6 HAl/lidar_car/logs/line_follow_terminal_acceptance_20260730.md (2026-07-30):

# Line-follow terminal acceptance — 2026-07-30

## Acceptance run

- Image: `LineFollowJY901Debug`.
- Frozen evidence: `line_follow_frozen_20260730-190434.log`.
- Run window: `t_ms=5995..35203` (`29.208 s`); `254` samples.
- Result: automatic stop accepted with `TERMINAL_REASON=A_RETURN_AFTER_2_ARCS`.
- JY901: `GYRO_STALE_RECORDS=0`; terminal status reported
  `lap_yaw_travel_tenths=-3323` and front/rear motors disabled.

## Terminal correction evidence

The preceding run stopped incorrectly in B--C with
`A_ARC_MARK_RETURN`. The official map contains two clockwise semicircles
(B--C and D--A), so a gray-only outer-right/wide signature cannot identify
A. The accepted image accumulates the direct JY901 yaw and enables the curved
A marker only after `330 deg` clockwise progress. B--C is therefore excluded;
the return A marker is accepted after the two arc phases.

## Control-quality observation for next iteration

- `|gray_err_x100| >= 400`: `182 / 254` samples (`71.7%`).
- Stable center `X4|X5=0x18`: `22 / 254` samples (`8.7%`).
- Maximum total differential: `2200 cps`; maximum target split: `2200 cps`.

The car completed the loop, but it spent too long using X7/X8-side recovery in
curves. Next work is **center attraction / anti-edge recovery** inside the
gray steering reference. It must not alter motor direction, speed-loop
polarity, JY901 source, or the accepted terminal gate.

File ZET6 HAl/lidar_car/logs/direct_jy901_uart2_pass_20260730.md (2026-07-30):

# Direct JY901 UART2 reception — 2026-07-30

## Wiring and test image

- Test image: `PwmGyroSweepDebug`; all motors remained stopped (`motion=S`).
- USART2 full remap: `PD5 = MCU TX -> JY901 RX`; `PD6 = MCU RX <- JY901 TX`.
- Gyro default: 9600 8N1; diagnostic UART: USART1 115200.

## Live serial evidence

Two `P` status requests on COM13, separated by two seconds:

| Field | First | Second | Delta |
| --- | ---: | ---: | ---: |
| `gyro_frames` | 2383 | 2418 | +35 |
| `angle_frames` | 1198 | 1215 | +17 |
| `raw_bytes` | 30618 | 31067 | +449 |
| `pd6_fall_edges` | 71981 | 73059 | +1078 |

`pd5_fall_edges=0` is expected because PD5 is the MCU transmit pin. The
increasing valid frames and PD6 edges prove that the JY901 TX reaches the STM32
RX pin and the WIT parser accepts angle frames. `rate_frames=0` in this sample;
derive rate from consecutive yaw samples if direct JY901 becomes the selected
line-follow heading source.

## Selected control source

The current `LineFollowJY901Debug` field image uses this verified direct JY901
stream as its only heading-assistance source. It derives yaw rate from
consecutive angle samples because `rate_frames=0` in the tested configuration.
UART4 Pi radar pose parsing remains a separately retained back-up and is not
mixed into this controller.

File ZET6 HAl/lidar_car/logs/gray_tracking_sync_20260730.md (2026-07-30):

# 灰度循迹接口纠正与重新测试检查点（2026-07-30）

## 有效硬件事实

用户提供的实物图确认模块为 Yahboom `YB-MVX05-V1.0`。排针丝印为
`5V / AD2 / AD1 / AD0 / OUT / GND`，并带有 X1--X8 的地址真值表。
模块内置 74HC4051 风格的数据选择器：MCU 输出三位地址，模块在 `OUT` 输出被选中
探头的数字值。蓝光版可用于白底黑线地图。

| 模块信号 | MCU 引脚 | 当前固件方向 |
| --- | --- | --- |
| `AD0` | `PC0` | GPIO 输出，地址 bit0 |
| `AD1` | `PC1` | GPIO 输出，地址 bit1 |
| `AD2` | `PC2` | GPIO 输出，地址 bit2 |
| `OUT` | `PG0` | GPIO 输入，所选头数字输出 |

地址 `000`--`111` 依次选择 X1--X8；固件将八个输出汇成 `raw_mask` 的 bit0--bit7。
以“所有探头都在白底”时的 `all_white_mask` 为基准，`active_mask = raw_mask XOR
all_white_mask`，因此不需要假定模块输出高/低代表黑线。

## 已废止的错误解释

此前将 `PC0/PC1/PC2` 配置成 ADC 输入是错误驱动。于是旧日志的 `adc0/adc1/adc2` 是
地址脚浮空/偏置读数，不是 X1--X8 的反射强度；其 x1/x2/x3 判定和任何 ADC 阈值均
不能用于循迹 PID。原始日志保留，仅作问题定位证据。

## 已完成的软件修正

- `bsp_gray_tracking.*`：改为 AD0/AD1/AD2 地址扫描 + PG0 数字读取；不用 `Delay_us()`
  破坏 SysTick 时间基。
- `app_gray_tracking_test.c`：输出 `raw_mask`、相对白底的 `active_mask` 与去抖
  `stable_mask`。
- `scripts/analyze_gray_mux_log.ps1`：输出逐头 `CHANNEL_SWITCH` 判定。
- `GrayTrackingDebug` 构建通过：FLASH `6400 B / 512 KB`，RAM `2008 B / 64 KB`；
  入口仍先调用 `MotorSafe_InitOff()`，前后 TB6612 关闭。

## 2026-07-30 mux8 全通道实机验收（完成）

已烧录安全的 `GrayTrackingDebug`（启动时仍执行 `MotorSafe_InitOff()`），通过 J-Link
CDC `COM13` 采集：`logs/gray_mux_retest_20260730-104601.log`。

- 全部探头白底、发送 `W` 后：`all_white_mask=0x00`；
- X1--X8 依次从白底移到黑线后，分析器均报告 `CHANNEL_SWITCH`；
- 一一对应关系为：`X1=0x01`、`X2=0x02`、`X3=0x04`、`X4=0x08`、
  `X5=0x10`、`X6=0x20`、`X7=0x40`、`X8=0x80`；
- X3 额外复测的黑线样本为 `0x04`，未出现 X4 的 `0x08`，未观察到相邻头串扰。

结论：`PC0/PC1/PC2 -> AD0/AD1/AD2`、`PG0 <- OUT`、X1--X8 地址顺序和蓝光模块的
白底黑线分辨能力均已实机确认。此前 ADC 记录仍只保留为错误定位归档。

## A 点全黑区域实测（2026-07-30 11:03）

用户确认当前整组探头位于 A 点（起点）的全黑区域。串口命令 `K` 采集黑色快照，日志
为 `logs/gray_mux_all_black_A_20260730-110324.log`：

- `cal_black`：`raw_mask=255`、`active_mask=255`、`stable_mask=255`；
- 随后约 4 s 连续 `sample` 均保持上述 `0xFF` 状态；
- 白底基准仍为 `0x00`，未被本次 `K` 命令改写。

全黑 A 点可以作为后续路线状态机的“位置确认”候选条件；根据当前任务规则，正式任务
启动仍必须由车上实体按键发起，不能由灰度全黑自动启动。

## 正常黑线居中零点实测（2026-07-30 11:06）

用户确认正常黑线居中时 X4 与 X5 同时触发。串口采集
`logs/gray_mux_center_x4_x5_20260730-110625.log` 中 24 条有效样本均为：

```text
raw_mask=24, active_mask=24, stable_mask=24   # 0x18 = X4 | X5
```

`0x18` 现作为灰度横向误差的零点掩码。该记录只证明“阵列索引居中”；尚未定义相对
车体左/右的误差正负，也尚未接入电机控制。

## 车体左/右误差符号实测（2026-07-30 11:15--11:16）

保持车头朝向后，用户按要求将正常黑线相对阵列从中心分别移向车体左、右侧：

| 位置 | 稳定掩码 | 样本 | 证据 |
| --- | --- | --- | --- |
| 车体左偏 | `0x08`（仅 X4） | 23/23 | `gray_mux_vehicle_left_x4_20260730-111544.log` |
| 居中 | `0x18`（X4+X5） | 24/24 | `gray_mux_center_x4_x5_20260730-110625.log` |
| 车体右偏 | `0x10`（仅 X5） | 23/23 | `gray_mux_vehicle_right_x5_20260730-111651.log` |

这确认 X1--X8 的阵列索引从车体左到右递增。安全诊断权重为
`-7/-5/-3/-1/+1/+3/+5/+7`；`err_x100` 的负值表示黑线在车体左，正值表示黑线在车体右。
仅灰度诊断输出允许使用此结论；还没有把误差接到任何电机输出。

## 误差诊断镜像烧录与串口回归（2026-07-30 11:19）

`GrayTrackingDebug` 已构建并通过 J-Link 烧录、逐段比较和复位运行：FLASH `7140 B /
512 KB`，RAM `2008 B / 64 KB`。`COM13` 回归日志
`logs/gray_error_diag_boot_20260730-111933.log` 已确认新字段输出：

```text
line_class,UNCAL,line_side,N/A,active_count,0,err_x100,0
```

烧录复位会清空 RAM 中的 `all_white_mask`，因此这条 `UNCAL` 记录是预期安全状态，
不是传感器故障。下一步必须先让八头同时位于白底并发送 `W`；校准后才可记录有效的
`LINE / LOST / A_MARK`、`line_side` 和 `err_x100`。电机保持关闭。

## 误差诊断三点回归（2026-07-30 11:20--11:22，完成）

新镜像复位后重新标定白底：`gray_error_diag_white_cal_20260730-112045.log`，
`all_white_mask=0x00`、`cal=1`。随后在同一白底基准下完成三点回归：

| 物理位置 | 实测稳定掩码 | 诊断输出 | 证据 |
| --- | --- | --- | --- |
| 正常居中 | `0x18`（X4+X5） | `LINE, CENTER, err_x100=0` | `gray_error_diag_center_20260730-112143.log` |
| 黑线在车体左 | `0x08`（X4） | `LINE, VEH_LEFT, err_x100=-100` | `gray_error_diag_vehicle_left_x4_20260730-112215.log` |
| 黑线在车体右 | `0x10`（X5） | `LINE, VEH_RIGHT, err_x100=100` | `gray_error_diag_vehicle_right_x5_20260730-112247.log` |

三组样本均持续约 4 s、无掩码跳变，证明 mux8 采样、3 次去抖、权重、中心零点和左右
符号在当前地图上闭合一致。允许把 `err_x100` 接入下一阶段的“仅计算控制量”循迹外环；
电机驱动输出仍必须保持断开，直到单独完成方向、限幅和失线保护测试。

## 后续受控步骤

1. 烧录 `mux8_control_dryrun`，重新白底标定；只验证 `ctrl_state`、`target_vx`、
   `steer_demand` 和 `steer_dir`，且 `motor_permit` 必须始终为 `0`。
2. 单独用前 TB6612 + 前编码器复验低速前进、左转和右转，确定控制意图到
   `Motion_Car_Control()` 的实际电机转向符号。
3. 速度闭环、陀螺仪修正和灰度外环必须按阶段叠加，不能跳过电机方向、限幅、失线和
   宽线保护验收。

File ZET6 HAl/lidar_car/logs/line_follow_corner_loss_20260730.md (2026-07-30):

# 无陀螺仪循迹：首个转弯丢线记录（2026-07-30）

- 镜像：`LineFollowNoGyroDebug`，PG10 从全黑 A 点启动。
- 结果：直线离开 A 点并进入循迹；第一个转弯后白底丢线，安全停止。
- 冻结证据：`line_follow_frozen_20260730-145950.log`，终止原因为
  `LINE_LOST_TIMEOUT`。
- 关键序列：传感器黑线由 X5（`0x10`）向 X6/X7/X8（最高 `0x80`）移动；
  最大灰度误差为 700。旧差速上限仅为 700 cps，丢线后又因当前灰度误差清零而
  以零差速盲行。
- 速度环证据：TRACK 段左右目标/实测平均总误差约 186 cps，非本次首要故障。
- 后续修正：外侧探头非线性差速上限提升至 1600 cps；无陀螺仪急弯降至
  220 mm/s；丢线时保留最后有效转向并以 180 mm/s 最多找线 650 ms。
- 验收待办：同一 A 点和同一首弯复测；必须导出新的冻结日志后才确认修正有效。
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

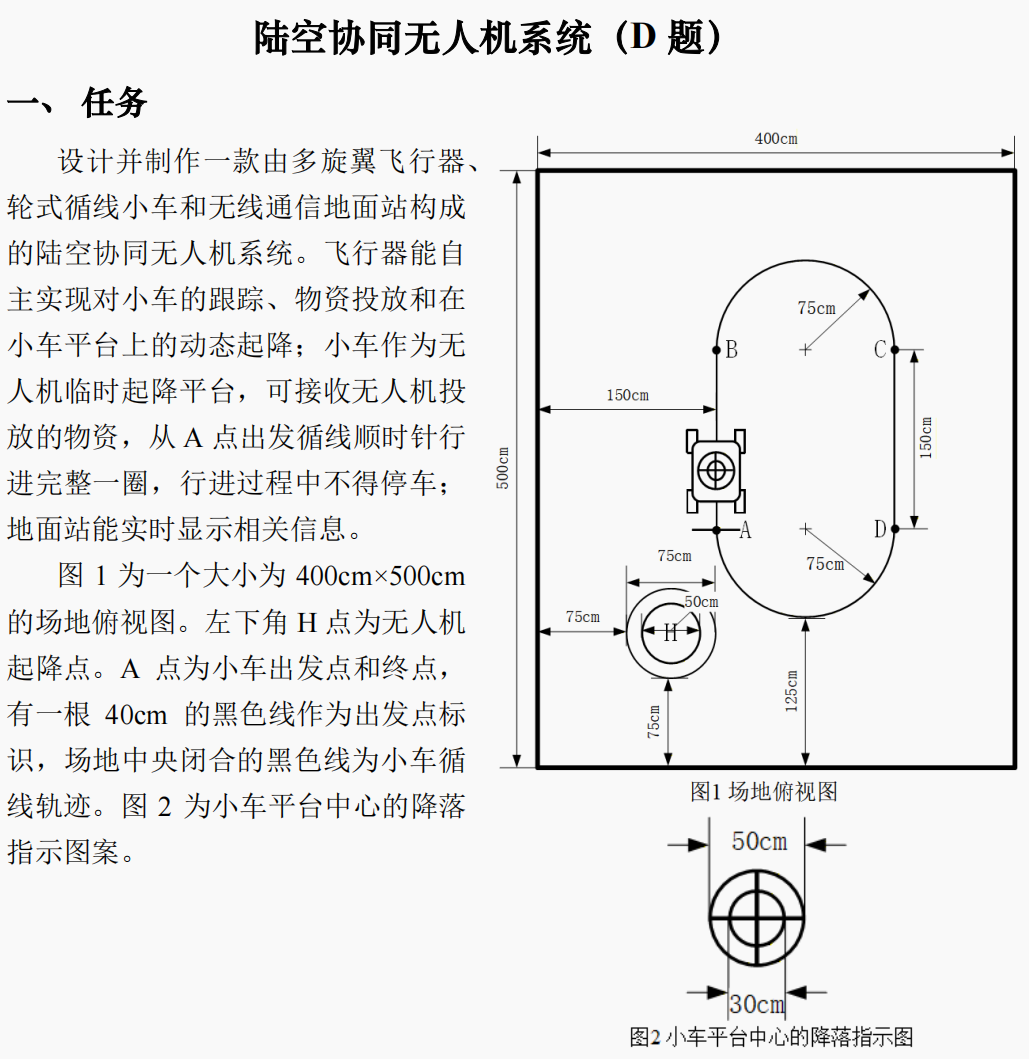
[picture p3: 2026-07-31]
ZET6 HAl/lidar_car/docs/地图描述.png

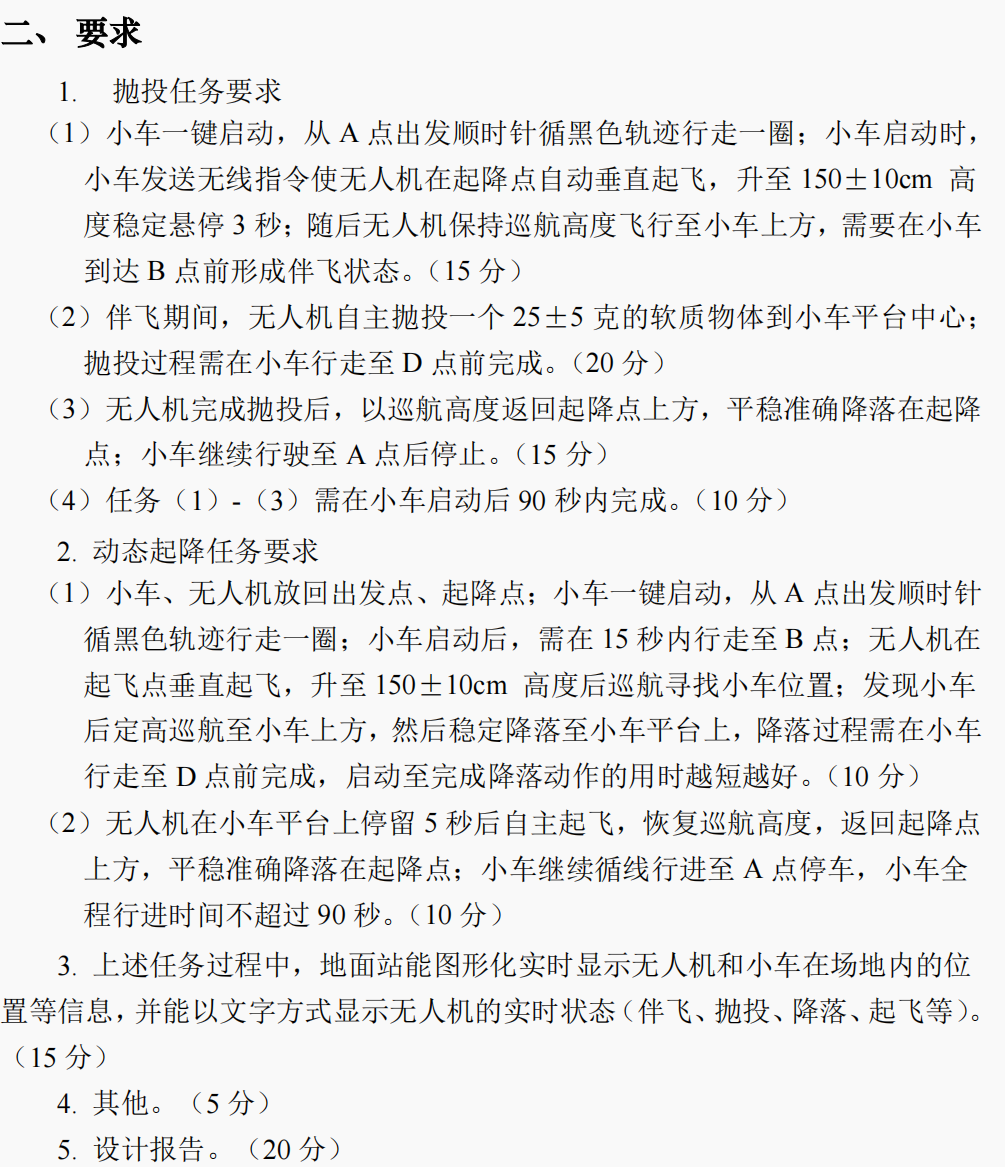
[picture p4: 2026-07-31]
ZET6 HAl/lidar_car/docs/任务要求.png

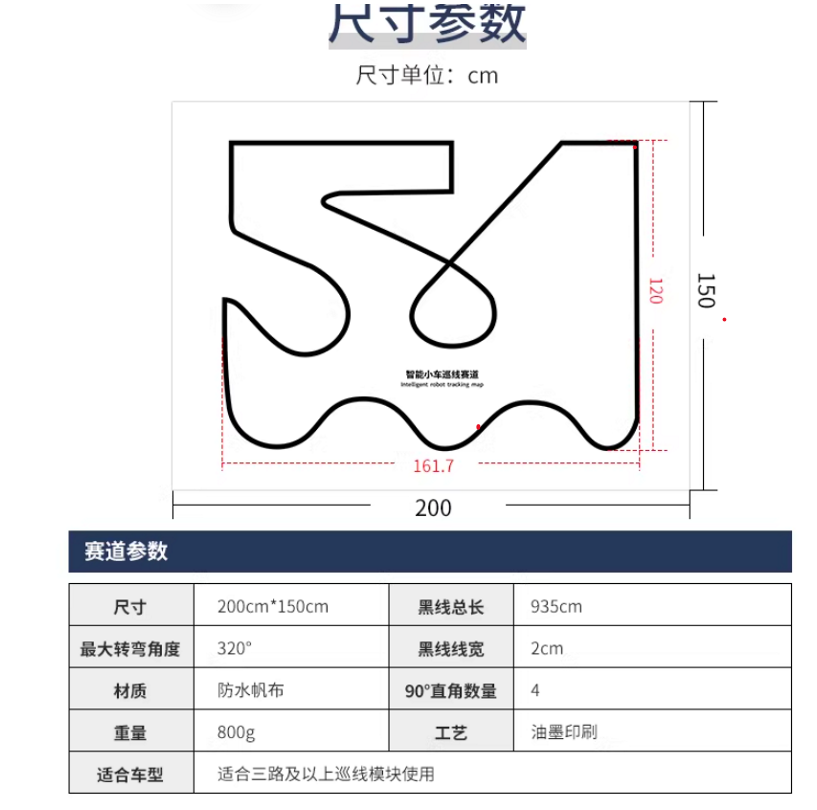
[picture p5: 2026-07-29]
tools/image.png

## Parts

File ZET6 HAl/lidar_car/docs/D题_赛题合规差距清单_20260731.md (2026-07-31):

# D 题赛题合规差距清单

更新时间：2026-08-01

> 本文件将“本地小车可运行”“无线链路可收发”和“可以主张赛题得分”严格分开。
> 权威通信要求以 `D题_通用通信与接口规范_v2.3.docx` 为准；题目和计时
> 以 `任务要求.png`、`D题 回复.txt` 为准。任何与这两份来源冲突的现场方案，
> 只能写为临时联调兼容方案，不能写为正式通过。

## 当前结论

`LineFollowMissionDebug` 已具备可继续联调的车端基础：PG13/PG9 任务选择和二次
急停、PG12 维护键、灰度/JY901/编码器循迹、12 s 失线搜索、20 s 卡滞保护、90 s
整圈计时、任务二 B 点 15 s 记录、`0x81/0x82/0x02/0x84` 框架均在小车工程内。

但截至本清单版本，**不能宣称满足 V2.3 的正式空地计分闭环**。原因不是编译或
小车循迹，而是坐标和校准所有权仍与权威协议不一致，且飞机、机载 ESP32、Pi 位姿桥、
地面站和实飞证据不在本仓库。

PG12 当前固件固定为停车后 50 ms 消抖的短按；它是当前 MCU-local 调试标准，不是
附录验收时序。权威 V2.3 附录要求的“静止 12 s + 长按 2--3 s”在当前固件中没有
兼容分支。无论按键时序如何，G3 的 Pi 清除/ACK 链路差距仍需单独关闭。

## 强制门槛

| 编号 | 权威要求 | 当前车端状态 | 计分影响 | 关闭条件 |
| --- | --- | --- | --- | --- |
| G1 | DOCX 3.1 要求 `CAR_POSE` 表示平台同心圆十字中心；当前单向 Pi 兼容链采用固定坐标约定 `X_lora=-(X_pi-13 cm)+DeltaX`、`Y_lora=-Y_pi+DeltaY`、`yaw_lora=yaw_pi` | 当前 MCU 已按该兼容公式发送，原始/出站的实车同心圆几何尚未留存证据 | 坐标符号、偏移或物理中心任一不一致都会使空侧/地面站位置错误 | 抓取 Pi 原始帧和 LoRa 出站帧逐帧验证该公式，并用场地实测证明其对应平台中心；未证明前不得主张严格通过 |
| G2 | 场地 Delta 由 Pi 应用；MCU 转发 `0x83`，等待 Pi 成功 ACK 后才对地面站 ACK（3.3、5.3、6.1） | 当前 MCU 本地保存 Delta 后直接 ACK 地面站 | 与发布的 V2.3 控制事务不一致 | 接通 `PC10 MCU TX -> Pi RX`，部署 Pi 校准 ACK；或取得赛题方对 MCU 所有权方案的书面确认并使所有端同步协议 |
| G3 | 附录 C 的物理触发是车辆静止至少 12 s 后 PG12 长按 2--3 s；正式链路还要求 Pi 先清校准、回 ACK，MCU 再发三帧 `0x85` | 当前固件固定为停车后 50 ms 消抖短按，MCU 直接清本地状态并广播；Pi 不参与 | 当前按键时序和复位所有权均与正式链路不一致，Pi 可能保留旧校准 | 获得赛题方对当前 MCU-local/短按方案的书面确认，或另行实现并验证附录时序与 Pi 清除/ACK 后广播；验证旧 ID 无法恢复 |
| G4 | 飞机只接受连续三帧新鲜、校准、平台中心 `CAR_POSE` 后的任务 | 当前原始 Pi V2.3 三帧/未校准约束尚在迁移；旧 `FA...AB` 仍可被用于出站兼容显示 | 旧流不能作为正式协同或得分证据 | 只允许 native V2.3 原始输入建立 `0x81`；Pi 重启后重新获得三帧有效输入和正式校准 |
| G5 | 小车开始运动时发出无线起飞任务，飞控仅在预检通过后 ACK；重发不重复触发 | 本地无雷达模式可先循迹、后补发 `0x81` | 无即时 `0x81`/ACK 的一圈只能证明循迹，不能证明任务一/二 | 正式起跑前完成 G1--G4 并录到同一轮 `motion_start -> 0x81 x3 -> ACK -> 0x82/0x02` |
| G6 | 车端 10 Hz、空端 2 Hz、100 ms 时隙、10 分钟错误统计 | 编码和调度已在 MCU 中；无完整三端 10 分钟实测 | 互操作未验收 | 保存地面站、车端、机端三份时间序列，统计 CRC/长度/乱序/丢帧 |
| G7 | 任务一抛投、任务二动态降落和再起飞、地面站实时图形显示 | 不在本仓库 | 80 分任务与 15 分地面站均不可由本工程单独获得 | 连续视频、飞控状态、地面站截图和验收记录齐全 |

## 可以继续的联调层级

| 层级 | 允许的结论 | 不允许的结论 |
| --- | --- | --- |
| L0 车端本地循迹 | 灰度/JY901/编码器、A 点停车、失线恢复、转弯与看门狗工作 | 任务一或任务二已得分 |
| L1 无线帧台架 | CRC、长度、地址、时隙、`0x81/0x82/0x02/0x84` 收发可观测 | 飞控实际接受任务或完成飞行动作 |
| L2 临时 MCU 本地校准 | MCU 本地 Delta、ACK、出站坐标变换可重复 | 已符合 DOCX 规定的 Pi 校准/复位事务或严格得分 |
| L3 正式计分联调 | 关闭 G1--G7 后，带 Pi/飞控/机载无线/地面站的完整场地运行 | 未留存端到端证据时的口头通过 |

## 本轮最小闭环顺序

1. 先决定正式策略：恢复 Pi 双向校准链路，或取得对 MCU 本地校准架构的明确协议变更。
2. 校验坐标映射：同时抓取 Pi 原始帧和 LoRa 出站帧，逐帧确认
   `X_lora=-(X_pi-13 cm)+DeltaX`、`Y_lora=-Y_pi+DeltaY`、`yaw_lora=yaw_pi`。只检查校准前后
   差值不足以证明镜像已生效。
3. 仅用 native V2.3 Pi 帧执行三帧就绪、`0x83`、三帧校准后 `CAR_POSE`、`0x85` 清除的
   台架闭环；当前短按 PG12 只能证明本工程的维护复位。若要按附录计分，另行完成
   静止/长按与 Pi 清除 ACK 的合规实现和证据。`FA...AB` 仅可留作迁移诊断。
4. 对每个任务录制从 `motion_start` 开始的完整证据：`0x81` 三次、空侧 ACK、阶段、B 点、
   A 点、90 s 与视频。任务二还必须有 15 s B 点和平台停留/再起飞证据。

## 证据命名

每次正式尝试建立同一时间戳目录，至少包含：

```text
acceptance.md
car_serial.log
ground_station.log
air_radio.log
flight.log
video.mp4
```

`acceptance.md` 必须写明镜像 SHA、硬件接线、Pi/飞控/地面站版本、场地、
`CalibrationId`、Delta、G1--G7 状态和最终结果。没有这些字段时，只能记录为
调试尝试，不能升级为计分证据。

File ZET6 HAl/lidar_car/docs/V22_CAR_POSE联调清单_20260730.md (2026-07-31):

# V2.3 CAR_POSE 与维护复位无线联调清单

> 文件名沿用历史 `V22`；通信权威已切换至 `D题_通用通信与接口规范_v2.3.docx`。
> 在线帧 Version 字段仍固定为 `0x02`。
> 当前任务按键、阶段门、计时和得分入口以
> [D题_V23_联调与计分矩阵.md](D题_V23_联调与计分矩阵.md) 为准；本页只记录
> 位姿链路和无线帧验收。
> MCU-local 校准是单向 Pi 硬件的兼容路径；严格 V2.3 和赛题得分门槛见
> [D题_赛题合规差距清单_20260731.md](D题_赛题合规差距清单_20260731.md)。

## 当前 MCU 实现

当前 `LineFollowMissionDebug` 已增加 `bsp_car_pose_link.*`：

1. UART4（PC11 MCU RX）以 115200 8N1 单向读取 Pi 的原始 V2.3 字节流；当前也兼容读取
   旧本地 `FA...AB` 14 B 帧。当前物理构型没有 MCU -> Pi 回传控制链路，MCU 不向 Pi
   发送 `0x83`、`0x85` 或 ACK；
2. 首选输入为 `AA 55 02 80 31 32 ...`、22 B payload、CRC16/CCITT-FALSE 正确的帧；
3. 要求 `CoordinateFrame=FIELD_GLOBAL(0x01)`、`POSITION_VALID` 与 `YAW_VALID` 均置位、
   yaw 在 ±180.0° 内；速度无效时 `Vx=Vy=0x7FFF` 且清 `VELOCITY_VALID`，
   速度有效时两个字段都不得为 `0x7FFF`。Pi 输入应保持 `CALIBRATED=0`、
   `CalibrationId=0`；即使上游遗留该标记，MCU 也不以它作为校准权威。重复/乱序
   `SourceTimeMs` 不更新原始状态；
4. 仅对接收年龄不超过 250 ms 的样本，以车端地址 `0x30` 和广播目的 `0x10` 重编码为
   33 B `CAR_POSE`，每 100 ms 发送一次。LoRa 出口的 X 先减固定 `13 cm`，
   再镜像 X/Y、后叠加校准：
   `X_lora=-(X_pi-13 cm)+DeltaX`、`Y_lora=-Y_pi+DeltaY`、`yaw_lora=yaw_pi`；
5. MCU 根据实际循迹状态写入或清除 `CAR_RUNNING`，保留原始 Pi 坐标、yaw、速度和
   `SourceTimeMs` 供内部使用；仅在出站帧覆盖 `CALIBRATED/CalibrationId`。PG13/PG9
   先启动本地任务，连续三帧原始位姿有效且 MCU 本地校准有效后才通过 UART5 发出
   `CAR_TASK_REQUEST(0x81)`；运行中 PG13/PG9 二次按键发送 `MISSION_ABORT(0x84)`。
   `CALIBRATION_SET(0x83)` 由 MCU 本地应用后直接回复地面站；PG12 的
   `MAINTENANCE_RESET(0x85)` 直接清除 MCU 本地状态后广播。旧 14 B 兼容流没有 Pi
   时间戳，使用独立的 MCU 转发 epoch。

当前路线本地参考：A=`(0.0,0.0) cm`、B=`(-151.3,-8.1) cm`、C=`(-165.7,150.7) cm`、
D=`(-16.5,164.2) cm`。A/B 航向约 `0°`，C/D 航向约 `180°`；现场 `0x83` 校准后才可
把它们映射为当日 FIELD_GLOBAL。它们仅作雷达辅助，
车辆循迹主判据仍是灰度、JY901 yaw/yaw-rate 和编码器累计路径距离。

## Pi 单向原始位姿输入要求

Pi 只需在 UART4 连接的 TX 线上按 10 Hz 发送原始雷达参考坐标。它不接收 MCU 指令，
不保存 `DeltaX/DeltaY/CalibrationId`，也不响应 `0x83/0x85`。当前 MCU 在 LoRa
出口承担固定 X 偏移、镜像和本地校准时，Pi 不得重复任一变换；MCU 先对 X 减
`13 cm`，再对 X/Y 取反，最后叠加校准偏移：

```text
V=02 Type=80 Src=31 Dst=32 Seq=递增 Flags=00 Len=16(hex)
Payload:
  CoordinateFrame=01
  PoseFlags: POSITION_VALID|YAW_VALID；CALIBRATED 清零
  CalibrationId: 0
  X/Y: 原始 FIELD_GLOBAL 雷达参考，i32 big-endian，cm
  Yaw: i16 big-endian，0.1 度，逆时针为正
  Vx/Vy: 有效则 i16 cm/s；无效则均为 0x7FFF 且清 VELOCITY_VALID
  SourceTimeMs: Pi 单调毫秒，u32 big-endian
CRC16/CCITT-FALSE: 覆盖 Version 至 Payload，CRC 高字节先发。
```

历史 14 B `FA...AB` 雷达帧可用作当前硬件的迁移输入。MCU 将它视为原始位姿；
只有在本地 `0x83` 已生效时，出站帧才携带 `CALIBRATED=1` 和本地
`CalibrationId`。它不含 CRC、速度有效性和 Pi 时间戳，正式任务仍优先使用前述
22 B 输入格式。

## 验收顺序

1. 恢复并 SSH 验证雷达 Pi，确认其 UART4 发射端连接到 `PC11` 且无其他设备占用。
2. 静止 A 点：地面站连续收到 10 Hz `CAR_POSE`；检查 `src=0x30,dst=0x10,len=22`、CRC=0、
   `CAR_RUNNING=0`、新鲜度小于 250 ms。
3. 执行起飞前校准：先记录一帧未校准的出站 `CAR_POSE`，再发送 `0x83`；确认 MCU
   直接 ACK，随后至少三帧出站位姿为 `CALIBRATED=1`、固定非零
   `CalibrationId`，且 X/Y 相对校准前的增量等于 Delta。Pi 输入始终保持原始位姿。
4. 在 A 点按 PG13（任务一）或 PG9（任务二）低速循迹：地面站检查连续 10 Hz、
   `CAR_RUNNING=1`，而不允许无线 ACK 改变电机状态；PG10 不应产生事件。
5. 断开 Pi UART：250 ms 后不再发送 `CAR_POSE`；跑动中无线静默，静止后恢复维护 HEARTBEAT；
   留存 STM32 冻结日志与地面站统计。

无 Pi 的本地循迹是允许的：PG13/PG9 仍由灰度、JY901 和编码器启动和运行。它不能作为
无人机协同得分证据；Pi 后续恢复合格位姿时可延后建立协同会话。要计入正式空地任务，
必须留存 MCU 本地校准后的三帧位姿、`0x81`/ACK 和空侧预检证据，但这些不是车辆启动前置。

## 0x83 / PG12 维护联调（当前 MCU-local 路径）

本清单执行当前短按标准：停车后短按 PG12。权威 V2.3 附录的“静止 12 s + 长按 2--3 s”
作为外部赛题条款和 G3 合规差距记录；当前固件没有该切换分支，也不能把两种触发条件
叠加或混称。单向 Pi 缺失的清除/ACK 闭环仍由 G3 单独跟踪。

1. 地面站只在收到 `CAR_POSE.Seq mod 5=2` 后的 30–50 ms 维护窗口发送定向
   `CALIBRATION_SET(0x83, Src=0x40,Dst=0x30,ACK_REQUIRED,len=12)`。Payload 是
   `DeltaX(i32 BE), DeltaY(i32 BE), CalibrationId(u16!=0), APPLY=0x01, Reserved=0`。
2. MCU 只在 `CAR_RUNNING=0` 且本地未运行时接受 `0x83`，校验
   `Src=0x40,Dst=0x30,ACK_REQUIRED,len=12,CalibrationId!=0,APPLY=0x01,Reserved=0` 后，
   将 `DeltaX/DeltaY/CalibrationId` 写入 MCU RAM。它在下一 0–25 ms 小车时隙直接回
   地面站 `ACK(Src=0x30,Dst=0x40,RequestSeq=地面站 Seq,ACK_ACCEPTED)`，不转发给 Pi，
   也不等待 Pi ACK。重复 `Src+Type+Seq` 请求按 5 s 去重；停车状态下新请求 Seq 可覆盖
   当前 MCU 本地校准，`DeltaX/DeltaY` 始终相对原始 Pi 坐标完整替换，绝不累加。
3. 成功后，MCU 的下一批出站 `CAR_POSE` 必须是 `FIELD_GLOBAL`、
   `CALIBRATED=1`、固定的非零 `CalibrationId`；连续三帧相对校准前出站帧的 X/Y
   增量必须等于本次 `DeltaX/DeltaY`。MCU 只在出站阶段计算校准坐标，内部原始 Pi/radar
   坐标不变。
4. **当前联调默认**中，PG12 为低有效物理维护键。车辆停止后短按并完成 50 ms 消抖，
   即由 MCU 立即清除本地 Delta、`CALIBRATED` 和 CalibrationId，并在连续三个小车时隙广播
   `Src=0x30,Dst=0x10,Type=0x85,len=8`；三帧 ResetId、Seq、payload 相同，后两帧仅加
   `RETRANSMISSION`。它不访问 Pi，无线侧也不等待 ACK；三帧完成后再次短按必须生成新的
   ResetId。行驶中按下仍不得产生 `0x85`。

   串口 `P` 应显示 `pg12_short_press_only=1`，并记录 `maint_reset_attempts`、
   `maint_reset_successes`、两类拒绝计数及 `maint_last_result`，用于确认每次短按的
   MCU 本地处理结果。

5. 调试重校准不必先按 PG12：保持停车，使用新的 `0x83` 请求 Seq 和新的 CalibrationId。
   若要验证校准前后差分，`X_after-X_before=DeltaX_new-DeltaX_old`，
   `Y_after-Y_before=DeltaY_new-DeltaY_old`；未记录旧 Delta 时只验证新 ID、ACK 和三帧输出。

## 2026-07-30 UART4 实测修复

旧的 UART4 前台轮询会在 UART5 LoRa 发送或诊断输出期间错过 115200 baud 的 Pi 字节，造成
`FA...AB` 旧桥接帧偶发失步，进而让地面站的 CAR_POSE 新鲜/失效状态切换。现已改为
`UART4_IRQHandler` 的 256 B 单生产者/单消费者接收环形缓冲；控制循环只从该缓冲解析帧。

静止小车、刚下载后的两次 COM13 `P` 状态回读为：

```text
t=13104 ms: raw=3668, legacy_ok=262, legacy_bad=0, uart_err=0, ring_ovf=0,
             x=6 cm, y=8 cm, yaw=9.5 deg, age=37 ms
t=18347 ms: raw=5138, legacy_ok=367, legacy_bad=0, uart_err=0, ring_ovf=0,
             x=6 cm, y=8 cm, yaw=9.6 deg, age=29 ms
```

即当前线上的原始帧为 `FA 00 00 00 06 00 00 00 08 00 00 00 60 AB`，按既有 14 B 协议解码就是
`(X,Y,yaw)=(6 cm,8 cm,9.6 deg)`，并非 MCU 大端重编码产生的大数。原点零位在本实测下仅有数厘米的
静止残差；原始 Pi/radar 输入不在 MCU 内部擅自平移。需要现场坐标对齐时，地面站使用
`0x83` 让 MCU 仅在 LoRa 出站阶段应用 Delta，并保留原始输入供循迹辅助。

### 冷启动 source-time 回归

旧 14 B 兼容流缺少 Pi 的 `SourceTimeMs`。若直接使用 MCU boot uptime，而雷达在 MCU 上电较久后才开始
输出，地面站会把低于上一会话的时间视为过期帧，即使 UART4 与 LoRa 都在持续工作。

现兼容路径从**第一个有效旧帧**开始独立的转发 epoch（随后按实际接收间隔递增）。这只解决地面站的重启
序判定，不伪称为 Pi 时间。冷启动后 MCU 状态为 `src_ms=16146, age=19 ms, legacy_ok=324,
legacy_bad=0, uart_err=0`；地面站在未重启状态下随即恢复 `car_age=0.000 s`，证明 source-time epoch
可跨 MCU 重启重新接入。

同一时刻 UART4 原始帧 `FA010001D8010000A70000027BAB` 解码为 `X=-472 cm,Y=-167 cm,yaw=63.5°`。
这是真实 Pi 桥接输入，不是 MCU/LoRa 载荷错误；雷达“上电置零”需在 Pi 雷达侧继续核对。

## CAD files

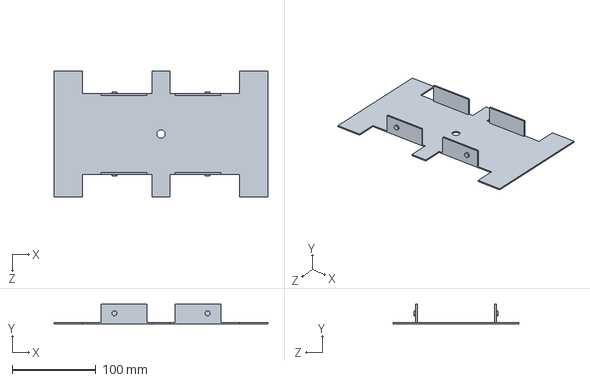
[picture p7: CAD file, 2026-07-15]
ZET6 HAl/lidar_car/双臂小车/小车/小车下底板.SLDPRT
255.0 x 23.6 x 150.0 mm

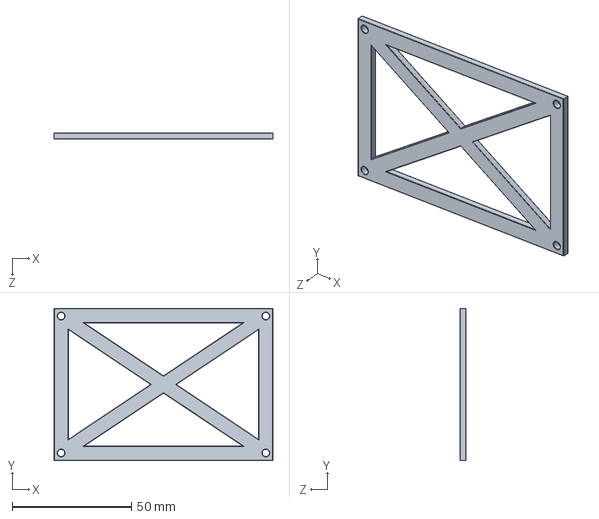
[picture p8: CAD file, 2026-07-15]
ZET6 HAl/lidar_car/双臂小车/开发板固定架等/Jason固定架.SLDPRT
92.0 x 64.0 x 2.60 mm

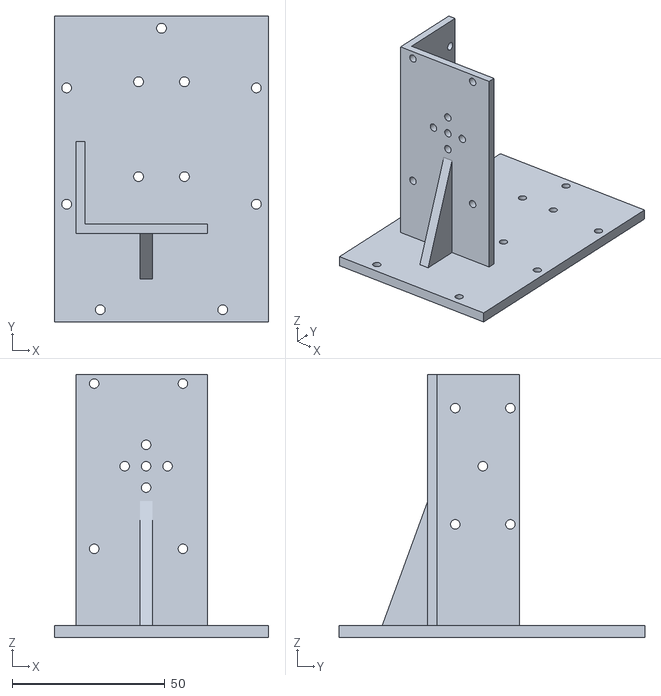
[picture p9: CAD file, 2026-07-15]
ZET6 HAl/lidar_car/双臂小车/机械臂/STL文件/左肩关节固定架.STL
70.0 x 100.0 x 86.0

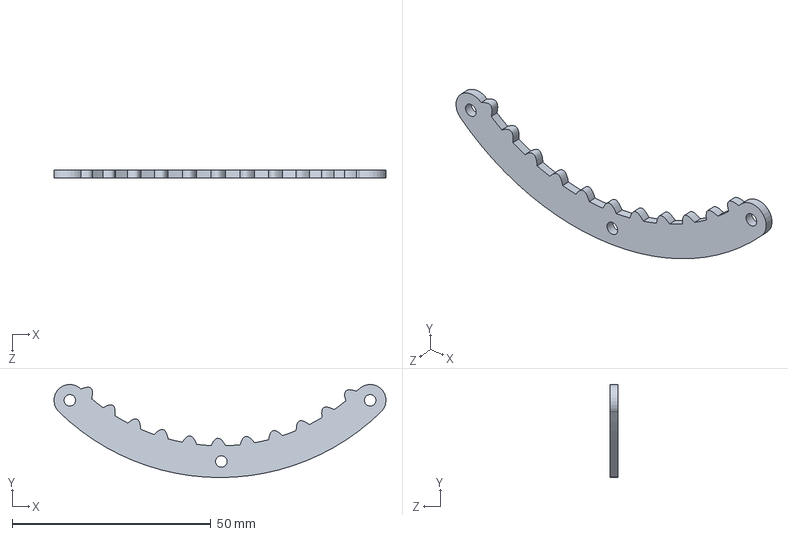
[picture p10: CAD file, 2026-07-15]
ZET6 HAl/lidar_car/双臂小车/机械臂/爪子/爪片.SLDPRT
83.6 x 23.4 x 2.00 mm

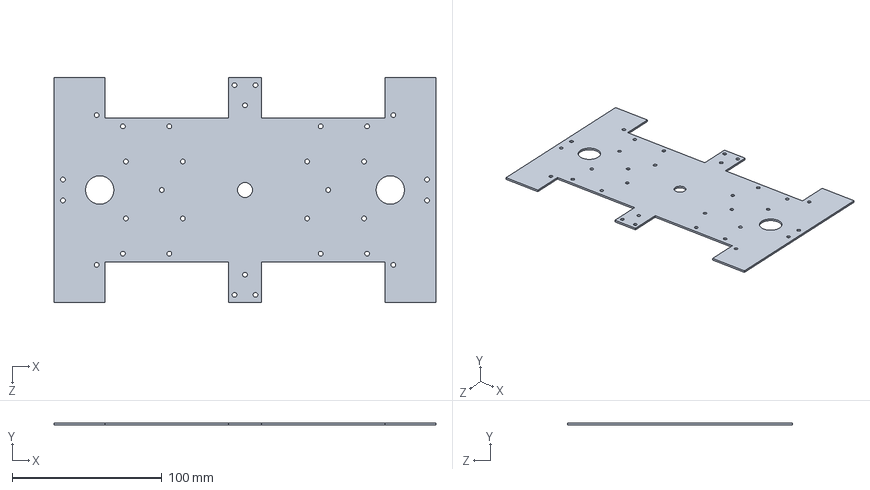
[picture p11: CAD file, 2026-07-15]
ZET6 HAl/lidar_car/双臂小车/小车/小车上底板.SLDPRT
255.0 x 1.60 x 150.0 mm

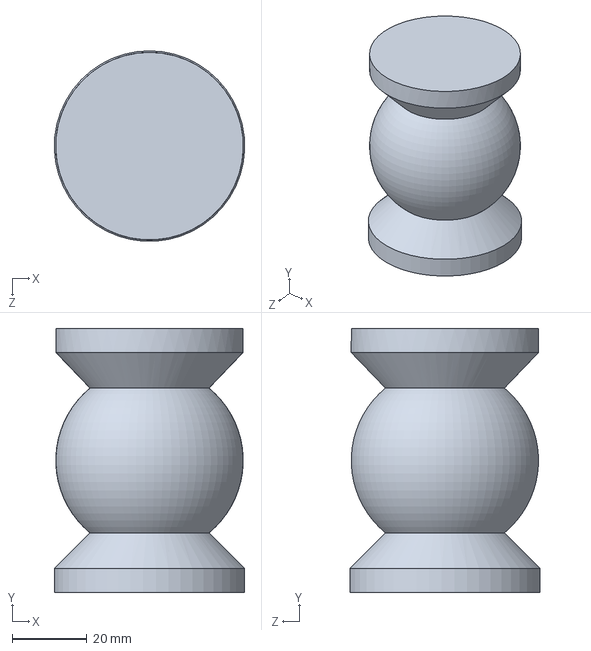
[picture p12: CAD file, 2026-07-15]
ZET6 HAl/lidar_car/双臂小车/开发板固定架等/工创棋子.SLDPRT
50.8 x 70.4 x 50.7 mm

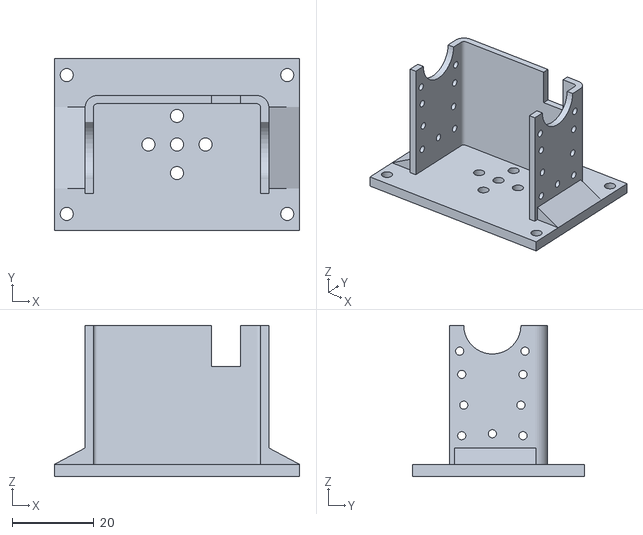
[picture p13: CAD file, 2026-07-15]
ZET6 HAl/lidar_car/双臂小车/机械臂/STL文件/固定架.STL
60.0 x 42.0 x 37.0

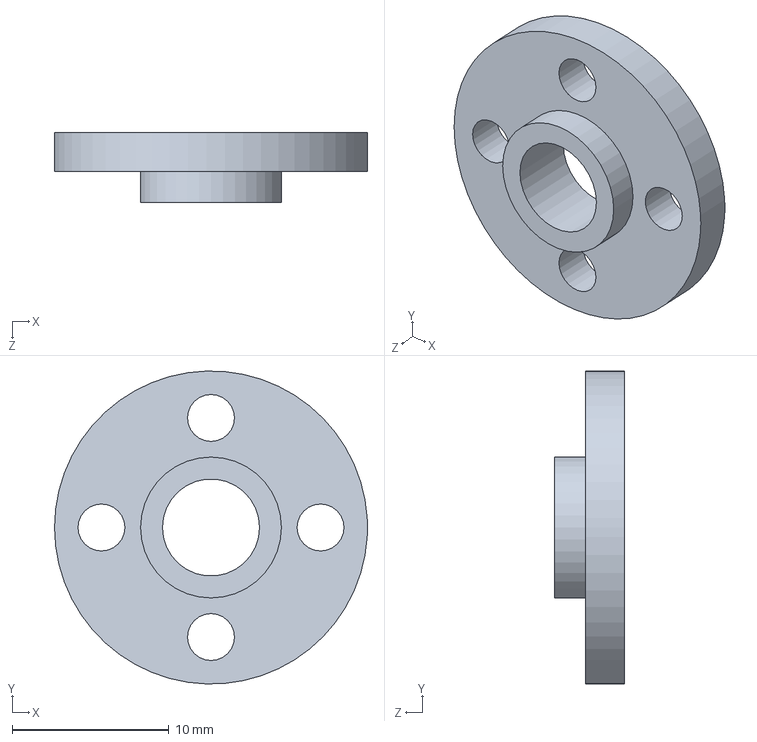
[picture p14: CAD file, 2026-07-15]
ZET6 HAl/lidar_car/双臂小车/机械臂/舵盘.SLDPRT
20.0 x 20.0 x 4.50 mm

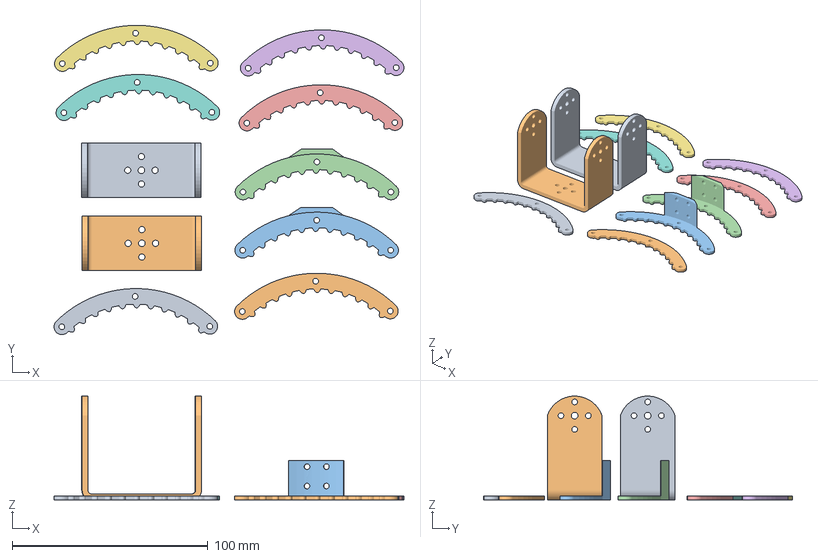
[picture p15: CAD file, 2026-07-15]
ZET6 HAl/lidar_car/双臂小车/机械臂/STL文件/大臂连杆.3mf
178.8 x 158.0 x 53.0 mm
U形支架.STL x 2
爪片连接.STL x 2
爪片.STL x 6

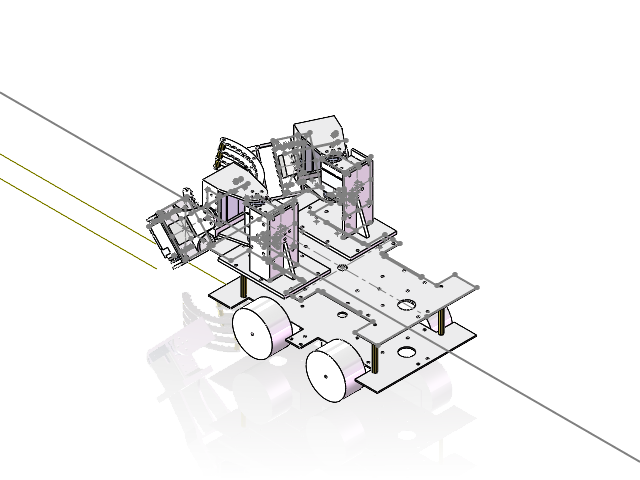
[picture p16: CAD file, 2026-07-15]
ZET6 HAl/lidar_car/双臂小车/双臂小车.SLDASM
小车下底板
仿车轮尺寸 x 4
60mm铜柱 x 4
小车上底板
手臂肩关节 x 2
SG_178.stp x 6
ZK_142.stp x 6
DG_130.stp x 6
GE_57.stp x 6
DUOPAN-SG.stp x 6
DUOPAN-DG.stp x 6
大臂连杆 x 2
固定架 x 2
U形支架 x 2
肩关节舵机固定 x 2
右肩关节固定架
左肩关节固定架
爪片连接 x 2
爪片 x 6
10mm铜柱 x 12

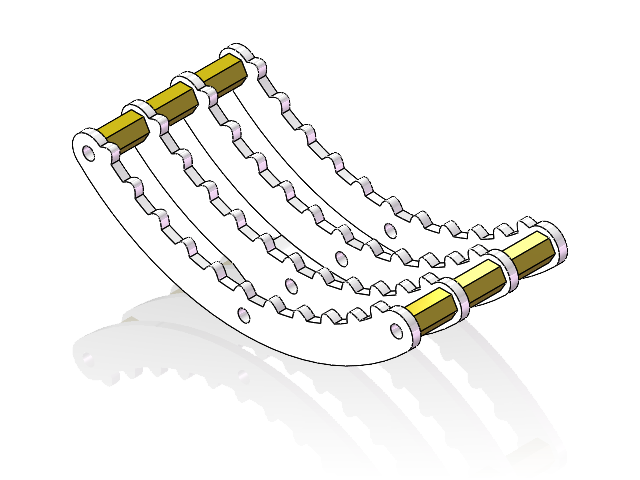
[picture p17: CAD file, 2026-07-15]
ZET6 HAl/lidar_car/双臂小车/机械臂/爪子/爪子.SLDASM
爪片连接
爪片 x 3
10mm铜柱 x 6

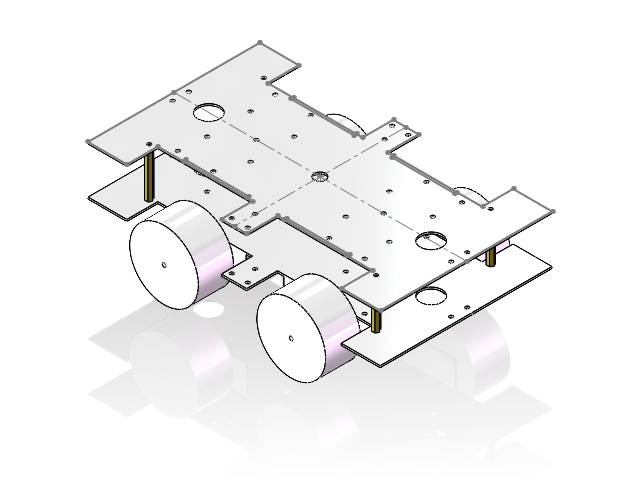
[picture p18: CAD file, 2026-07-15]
ZET6 HAl/lidar_car/双臂小车/小车/小车基础模型.SLDASM
小车下底板
仿车轮尺寸 x 4
60mm铜柱 x 4
小车上底板

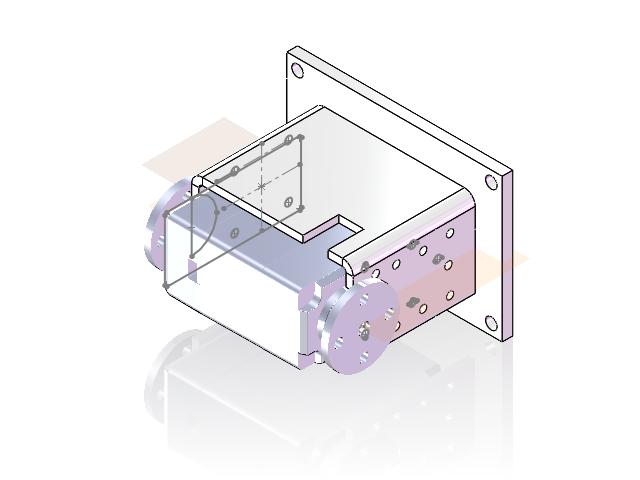
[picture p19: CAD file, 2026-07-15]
ZET6 HAl/lidar_car/双臂小车/机械臂/双轴舵机和固定架.SLDASM
固定架
SG_178.stp
ZK_142.stp
DG_130.stp
GE_57.stp
DUOPAN-SG.stp
DUOPAN-DG.stp

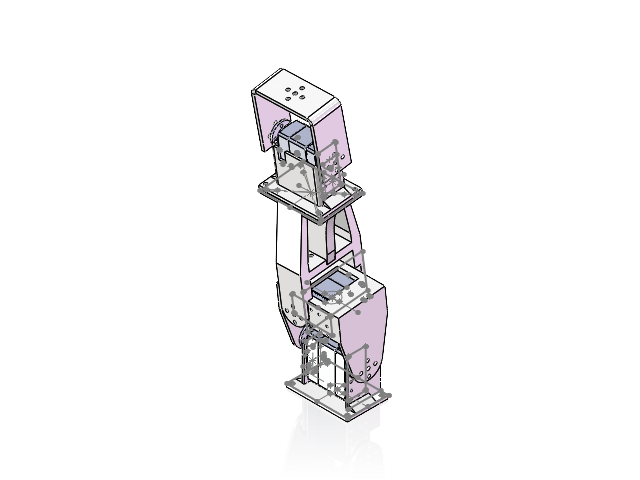
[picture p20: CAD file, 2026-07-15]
ZET6 HAl/lidar_car/双臂小车/机械臂/肩关节加大臂.SLDASM
手臂肩关节
SG_178.stp x 3
ZK_142.stp x 3
DG_130.stp x 3
GE_57.stp x 3
DUOPAN-SG.stp x 3
DUOPAN-DG.stp x 3
大臂连杆
固定架
U形支架
肩关节舵机固定

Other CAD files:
ZET6 HAl/lidar_car/双臂小车/机械臂/双轴舵机-260528/双轴舵机-260528.sldasm
ZET6 HAl/lidar_car/双臂小车/机械臂/双轴舵机-260528/双轴舵机-260528/双轴舵机-260528.stp.sldasm
ZET6 HAl/lidar_car/双臂小车/机械臂/双轴舵机-260528/双轴舵机-260528/ZK_142.stp.sldprt
ZET6 HAl/lidar_car/双臂小车/机械臂/左肩关节固定架.SLDPRT
ZET6 HAl/lidar_car/双臂小车/小车/60mm铜柱.SLDPRT
ZET6 HAl/lidar_car/双臂小车/小车/仿车轮尺寸.SLDPRT
ZET6 HAl/lidar_car/双臂小车/开发板固定架等/Jason固定架.STL
ZET6 HAl/lidar_car/双臂小车/开发板固定架等/工创棋子.STL
ZET6 HAl/lidar_car/双臂小车/机械臂/STL文件/U形支架.STL
ZET6 HAl/lidar_car/双臂小车/机械臂/STL文件/右肩关节固定架.STL
ZET6 HAl/lidar_car/双臂小车/机械臂/STL文件/大臂连杆.STL
ZET6 HAl/lidar_car/双臂小车/机械臂/STL文件/手臂肩关节.STL
ZET6 HAl/lidar_car/双臂小车/机械臂/STL文件/爪片.STL
ZET6 HAl/lidar_car/双臂小车/机械臂/STL文件/爪片连接.STL
ZET6 HAl/lidar_car/双臂小车/机械臂/STL文件/肩关节舵机固定.STL
ZET6 HAl/lidar_car/双臂小车/机械臂/STL文件/舵盘.STL
ZET6 HAl/lidar_car/双臂小车/机械臂/U形支架.SLDPRT
ZET6 HAl/lidar_car/双臂小车/机械臂/双轴舵机-260528/双轴舵机-260528/DG_130.stp.sldprt
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

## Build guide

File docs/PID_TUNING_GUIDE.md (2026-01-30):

# PID 调参计划

## 一、系统参数总结

### 硬件参数
| 参数 | 值 |
|---|-----|
| 电机型号 | MG310 (1:20 减速比) |
| 编码器 | 11线霍尔，4倍频 = 880脉冲/转 |
| 轮子直径 | 48mm (周长 150.7mm) |
| 最大速度 | ~2000 mm/s (100% PWM) |
| 死区 | 左 4%，右 5% |
| 控制周期 | 20ms (50Hz) |
| 循迹传感器 | 8通道，60mm宽度 |

### 编码器方向配置
| 轮子 | 反转设置 | 说明 |
|---|---|---|
| 左轮 | `countL = -countL` | 需要反转 |
| 右轮 | 不反转 | 原始方向正确 |

---

## 二、PID 架构

```
┌─────────────────────────────────────────────────────────────┐
│                    循迹 PID (外环)                           │
│  文件: app_control.c                                        │
│  输入: 循迹误差 (-30 ~ +30)                                  │
│  输出: 转向速度 Vz                                           │
│  频率: 50Hz                                                 │
└─────────────────────────────────────────────────────────────┘
                              ↓
┌─────────────────────────────────────────────────────────────┐
│                    速度 PID (内环)                           │
│  文件: app_motor.c                                          │
│  输入: 目标速度 vs 实际速度 (mm/s)                           │
│  输出: PWM 占空比 (0-100%)                                   │
│  频率: 50Hz                                                 │
└─────────────────────────────────────────────────────────────┘
```

**调参原则：先调内环（速度环），再调外环（循迹环）**

---

## 三、第一阶段：速度环调参

### 3.1 目标
让电机能准确跟踪目标速度，响应快、无超调

### 3.2 参数位置
文件：`Hardware/app_motor.c`

```c
#define MOTOR_SPEED_MAX_MMS     2000.0f     // 最大速度
#define MOTOR_DEADZONE_L_PCT    4           // 左轮死区
#define MOTOR_DEADZONE_R_PCT    5           // 右轮死区
#define MOTOR_PID_KP            0.08f       // 比例系数
#define MOTOR_PID_KI            0.02f       // 积分系数
#define MOTOR_PID_KD            0.0f        // 微分系数
```

### 3.3 调参步骤

#### 步骤 1：纯 P 控制
```c
#define MOTOR_PID_KP  0.05f
#define MOTOR_PID_KI  0.0f
#define MOTOR_PID_KD  0.0f
```

**测试方法：**
1. 设置目标速度 500 mm/s
2. 观察实际速度是否接近目标
3. 如果响应慢，增大 Kp
4. 如果震荡，减小 Kp

**Kp 调整参考：**
| 现象 | 调整 |
|---|---|
| 响应慢，达不到目标 | Kp × 1.5 |
| 轻微震荡 | Kp × 0.8 |
| 剧烈震荡 | Kp × 0.5 |

#### 步骤 2：加入 I 控制
当 P 控制稳定后，加入 I 消除静差：

```c
#define MOTOR_PID_KI  0.01f  // 从小值开始
```

**调整方法：**
- 如果静差消除太慢，增大 Ki
- 如果出现震荡，减小 Ki
- Ki 通常是 Kp 的 1/4 ~ 1/10

#### 步骤 3：D 控制（可选）
速度环通常不需要 D，但如果需要抑制超调：

```c
#define MOTOR_PID_KD  0.001f  // 非常小的值
```

### 3.4 速度环验证
创建测试程序，验证速度跟踪效果：

```c
// 在 main.c 中测试
void SpeedLoopTest(void)
{
    static uint32_t lastMs = 0;
    static int step = 0;
    uint32_t now = SysTick_GetMs();
    
    if (now - lastMs > 2000)  // 每2秒切换
    {
        lastMs = now;
        step = (step + 1) % 4;
    }
    
    switch (step)
    {
        case 0: Motion_Car_Control(300, 0, 0); break;  // 低速
        case 1: Motion_Car_Control(600, 0, 0); break;  // 中速
        case 2: Motion_Car_Control(300, 0, 0); break;  // 低速
        case 3: Motion_Car_Control(0, 0, 0);   break;  // 停止
    }
}
```

**验证标准：**
- [ ] 速度误差 < 10%
- [ ] 无明显震荡
- [ ] 启动/停止平滑

---

## 四、第二阶段：循迹环调参

### 4.1 目标
让小车能平稳跟踪黑线，转弯流畅

### 4.2 参数位置
文件：`Hardware/app_control.c`

```c
#define TRACK_BASE_SPEED    300     // 基础速度 (mm/s)
#define TRACK_PID_KP        15.0f   // 比例系数
#define TRACK_PID_KI        0.0f    // 积分系数
#define TRACK_PID_KD        5.0f    // 微分系数
```

### 4.3 调参步骤

#### 步骤 1：确定基础速度
从低速开始：
```c
#define TRACK_BASE_SPEED  200  // 先用低速
```

#### 步骤 2：纯 P 控制
```c
#define TRACK_PID_KP  10.0f
#define TRACK_PID_KI  0.0f
#define TRACK_PID_KD  0.0f
```

**测试方法：**
1. 放在直线上，观察是否能保持直行
2. 放在弯道上，观察能否跟踪

**Kp 调整：**
| 现象 | 调整 |
|---|---|
| 转弯不够，冲出线 | Kp × 1.5 |
| 左右摇摆 | Kp × 0.7 |
| 剧烈抖动 | Kp × 0.5 |

#### 步骤 3：加入 D 控制
D 控制对循迹非常重要，能抑制摇摆：

```c
#define TRACK_PID_KD  3.0f  // 从 Kp/3 开始
```

**调整方法：**
- 如果还在摇摆，增大 Kd
- 如果响应变慢，减小 Kd
- Kd 通常是 Kp 的 1/3 ~ 1/2

#### 步骤 4：I 控制（通常不需要）
循迹一般不需要 I 控制，因为：
- 误差是位置误差，不是速度误差
- I 会导致积分饱和问题

### 4.4 循迹验证

**测试场景：**
1. 直线：应该平稳直行
2. 缓弯：应该平滑转弯
3. 急弯：应该能跟上
4. S弯：应该流畅通过

**验证标准：**
- [ ] 直线无明显摇摆
- [ ] 弯道不冲出线
- [ ] 无剧烈抖动

---

## 五、参数推荐值

### 5.1 保守参数（稳定优先）
```c
// 速度环
#define MOTOR_PID_KP  0.05f
#define MOTOR_PID_KI  0.01f
#define MOTOR_PID_KD  0.0f

// 循迹环
#define TRACK_BASE_SPEED  200
#define TRACK_PID_KP  10.0f
#define TRACK_PID_KI  0.0f
#define TRACK_PID_KD  3.0f
```

### 5.2 中等参数（平衡）
```c
// 速度环
#define MOTOR_PID_KP  0.08f
#define MOTOR_PID_KI  0.02f
#define MOTOR_PID_KD  0.0f

// 循迹环
#define TRACK_BASE_SPEED  300
#define TRACK_PID_KP  15.0f
#define TRACK_PID_KI  0.0f
#define TRACK_PID_KD  5.0f
```

### 5.3 激进参数（速度优先）
```c
// 速度环
#define MOTOR_PID_KP  0.12f
#define MOTOR_PID_KI  0.03f
#define MOTOR_PID_KD  0.001f

// 循迹环
#define TRACK_BASE_SPEED  500
#define TRACK_PID_KP  20.0f
#define TRACK_PID_KI  0.0f
#define TRACK_PID_KD  8.0f
```

---

## 六、调试技巧

### 6.1 使用 OLED 显示
```c
// 显示关键变量
OLED_ShowNum(0, 0, targetSpeed, 4);
OLED_ShowNum(0, 2, actualSpeed, 4);
OLED_ShowNum(0, 4, trackError, 3);
OLED_ShowNum(0, 6, pwmOutput, 3);
```

### 6.2 使用串口输出
```c
// 每 100ms 输出一次
printf("T:%d A:%d E:%d P:%d\r\n", 
       targetSpeed, actualSpeed, trackError, pwmOutput);
```

### 6.3 常见问题排查

| 问题 | 可能原因 | 解决方案 |
|---|---|---|
| 原地打转 | 编码器方向错误 | 检查 ENCODER_x_INVERT |
| 速度不稳 | Kp 太大 | 减小速度环 Kp |
| 跟不上线 | Kp 太小 | 增大循迹环 Kp |
| 左右摇摆 | Kd 太小 | 增大循迹环 Kd |
| 冲出弯道 | 速度太快 | 减小 BASE_SPEED |

---

## 七、调参记录表

| 日期 | Kp | Ki | Kd | 速度 | 效果 | 备注 |
|---|-----|-----|-----|---|---|---|
| | | | | | | |
| | | | | | | |
| | | | | | | |

---

## 八、下一步计划

1. [ ] 关闭测试模式，恢复正常循迹
2. [ ] 从保守参数开始测试
3. [ ] 逐步调整速度环
4. [ ] 验证速度环后调整循迹环
5. [ ] 记录每次调整的效果

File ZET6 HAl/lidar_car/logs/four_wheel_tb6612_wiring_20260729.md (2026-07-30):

# Four-Wheel TB6612 Test Wiring

This is the active pin assignment for the `FourWheelTb6612Debug` test image.
The front TB6612 wiring remains unchanged. The rear TB6612 uses the new pins
below. All grounds, including the motor supply ground, TB6612 ground, and MCU
ground, must be common.

## Front TB6612

| Signal | STM32 pin | Function |
|---|---|---|
| PWMA | PA2 | TIM2_CH3 PWM |
| PWMB | PA3 | TIM2_CH4 PWM |
| AIN1 / AIN2 | PE2 / PE3 | Left-front direction GPIO |
| BIN1 / BIN2 | PE4 / PE5 | Right-front direction GPIO |
| STBY | PE6 | Front driver enable |
| Left encoder A / B | PA0 / PA1 | TIM5_CH1 / CH2 |
| Right encoder A / B | PA6 / PA7 | TIM3_CH1 / CH2 |

## Rear TB6612

| Signal | STM32 pin | Function |
|---|---|---|
| PWMA | PE13 | TIM1_CH3 PWM, full remap |
| PWMB | PE14 | TIM1_CH4 PWM, full remap |
| AIN1 / AIN2 | PF1 / PF2 | Left-rear direction GPIO |
| BIN1 / BIN2 | PF3 / PF4 | Right-rear direction GPIO |
| STBY | PB9 | Rear driver enable |
| Left encoder A / B | PB6 / PB7 | TIM4_CH1 / CH2 |
| Right encoder A / B | PC6 / PC7 | TIM8_CH1 / CH2 |

Connect TB6612 `A01/A02` to the left-rear motor `M+/M-`, and `B01/B02` to the
right-rear motor `M+/M-`. If a wheel moves opposite to the required vehicle
direction, swap that motor's `M+` and `M-` leads or invert only that motor in
software after the test has established its physical direction.

The competition gray module uses `PC0/PC1/PC2` as `AD0/AD1/AD2` address outputs
and `PG0` as selected digital `OUT`; `PG1` is unused. It has no known pin conflict
with this rear bench mapping. The four-wheel test image still does not initialize
gray decoding or line following.

## Direction Calibration

The 2026-07-30 PB9 test established the signs that make `G` command physical
vehicle forward. These signs apply only to `FourWheelTb6612Debug`:

| Wheel | Forward sign |
| --- | --- |
| Front-left | -1 |
| Front-right | -1 |
| Rear-left | +1 |
| Rear-right | -1 |

## Test Image

Build and flash `FourWheelTb6612Debug`:

```powershell
.\scripts\jlink_flash_four_wheel_tb6612.ps1
```

On reset, the firmware waits one second, drives all four motors at 65% PWM for
four seconds, then coasts and disables both TB6612 modules. USART1 logs use
`PA9/PA10` at 115200 baud.

| Serial command | Action |
|---|---|
| `G` | Run all four wheels forward for four seconds |
| `B` | Run all four wheels reverse for four seconds |
| `S` | Stop and disable both drivers immediately |
| `H` | Print command help |

The current test polls the rear encoder pins for transition diagnostics. It
does not yet enable TIM4/TIM8 hardware encoder mode; that belongs in the
closed-loop four-wheel control implementation after motor direction is fixed.

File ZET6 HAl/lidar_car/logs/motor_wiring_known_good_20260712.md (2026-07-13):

# Motor Wiring Known-Good

## Rear L298N

- ENA / left rear PWM: PA6, TIM3_CH1
- IN1: PC6
- IN2: PG1
- ENB / right rear PWM: PA7, TIM3_CH2
- IN3: PE9
- IN4: PE7
- `PC6=1, PG1=0`: left rear backward
- `PC6=0, PG1=1`: left rear forward
- `PE9=1, PE7=0`: right rear forward
- `PE9=0, PE7=1`: right rear backward
- PE8 is not used because it failed the ODR/IDR and motion tests

## Front TB6612

- PWMA / left front PWM: PA2, TIM2_CH3
- AIN1: PE2
- AIN2: PE3
- PWMB / right front PWM: PA3, TIM2_CH4
- BIN1: PE4
- BIN2: PE5
- STBY: PE6
- `PE2=1, PE3=0`: left front backward
- `PE2=0, PE3=1`: left front forward
- `PE4=1, PE5=0`: right front forward
- `PE4=0, PE5=1`: right front backward

## Four-Wheel Direction Checkpoint (2026-07-13)

- Test order: left front, right front, left rear, right rear
- Each wheel: first polarity 2 s, stop 1 s, opposite polarity 2 s
- Wheel-to-wheel pause: 2 s
- Cycle pause: 3 s, then repeat
- Front enable: PA2/PWMA, PA3/PWMB, PE6/STBY
- Rear enable: PA6/ENA, PA7/ENB
- Verified physical sequence: LF backward/forward, RF forward/backward,
  LR backward/forward, RR forward/backward

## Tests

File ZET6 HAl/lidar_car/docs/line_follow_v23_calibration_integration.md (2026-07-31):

# V2.3 Calibration Integration

This page is the current car-side integration checklist. The historical
`radar_pose_line_follow_switch_20260730.md` describes the migration from the
14-byte radar stream; it does not replace the V2.3 calibration transaction.

> 当前文中 MCU-local 路径是针对单向 `Pi TX -> MCU RX` 物理现状的**兼容联调**。
> 发布 V2.3 要求 Pi 承担平台中心换算与校准/复位 ACK；二者的差距、几何验证和
> 计分限制见 [D题_赛题合规差距清单_20260731.md](D题_赛题合规差距清单_20260731.md)。
> 未关闭这些门槛前，本页的成功条件只能证明车端/无线互操作，不能证明正式得分。

## Current MCU behavior

| Item | Implemented car behavior |
| --- | --- |
| `0x80 CAR_POSE` | Pi sends raw `0x31 -> 0x32` only; MCU retains it unchanged internally and publishes `0x30 -> 0x10` at 10 Hz. The LoRa egress mapping is `X_lora=-(X_pi-13 cm)+DeltaX`, `Y_lora=-Y_pi+DeltaY`, `yaw_lora=yaw_pi`; local `CALIBRATED/CalibrationId` is written after that mapping. |
| `0x83 CALIBRATION_SET` | Ground station sends `0x40 -> 0x30`, `ACK_REQUIRED`, 12-byte payload. MCU accepts it only while the car is not running, commits `DeltaX/DeltaY/CalibrationId` to MCU RAM, and replies directly to ground in the next car slot. It does not transmit to or wait for Pi. A new request sequence may replace an existing local calibration for debugging; the received Delta is always the complete offset from raw Pi pose, never an increment. Repeated `Src+Type+Seq` requests are deduplicated for 5 seconds. |
| `0x85 MAINTENANCE_RESET` | A stopped-car PG12 short press after 50 ms debounce clears the MCU-local Delta, `CALIBRATED`, and CalibrationId, then broadcasts three LoRa copies directly. Pi is not queried. The firmware has no long-press compatibility branch. |
| Local fallback | PG13/PG9 require the A marker and fresh JY901 only. Missing, stale, or implausible Pi/radar data records `task_coordination_deferred` while gray/JY901/encoder line following continues. Three valid raw pose samples plus MCU-local calibration may establish `0x81` later without restarting or stopping the car. |
| Task 1 speed | PG13 uses a 130 mm/s cooperative straight-line target. Existing curve, wide-line, and lost-line caps remain in force. |
| Task 2 speed | PG9 uses a 150 mm/s cooperative straight-line target. Existing curve, wide-line, and lost-line caps remain in force. |

## PG12 Standard Boundary

`LineFollowMissionDebug` implements only the short-press procedure. It must not
be described as requiring 12 s stationary or a long hold. The authoritative
V2.3 Appendix timing procedure remains an external scoring requirement and does
not close the separate Pi ownership/ACK gap documented in G3; it is not a CMake
option or a second physical button behavior in this firmware.

## Physical topology and ownership

The installed Pi link is one-way: `Pi TX -> MCU UART4 PC11 RX`. Pi sends raw pose
data only. It does not receive MCU messages, store `DeltaX/DeltaY/CalibrationId`,
or return a control ACK. The MCU is the calibration owner:

`Ground 0x83 -> MCU local RAM -> MCU ground ACK`

`Pi raw pose -> MCU raw internal state -> MCU calibrated LoRa CAR_POSE`

The Pi input contract is therefore limited to a fresh raw `CAR_POSE(0x80)` at 10 Hz:

1. Send `Src=0x31,Dst=0x32` with valid CRC, `FIELD_GLOBAL`,
   `POSITION_VALID|YAW_VALID`, raw X/Y/yaw, and a monotonic source time.
2. Keep `CALIBRATED=0` and `CalibrationId=0`. An upstream legacy mark is not
   trusted or echoed as MCU calibration.
3. Do not apply the center offset, mirror mapping, or site Delta in this
   compatibility input stream. MCU egress computes
   `X_lora=-(X_pi-13 cm)+DeltaX` and `Y_lora=-Y_pi+DeltaY`; yaw is
   relayed unchanged as `yaw_lora=yaw_pi`.

On a valid stopped-car `0x83`, the MCU validates source/destination, ACK flag,
12-byte payload, nonzero CalibrationId, `APPLY=0x01`, and reserved byte. It stores
the three calibration values in RAM, queues `ACK_ACCEPTED` directly to the ground
station, and leaves raw Pi/radar state untouched. It deduplicates the same
`Src+Type+Seq` for five seconds. A stopped car may accept a new request
sequence and replace an existing local calibration. For a changed offset, use
a new CalibrationId; do not add the new Delta to the previous one.

The observed legacy `FA ... AB` stream remains an allowed raw migration input. It
cannot ACK anything, and no ACK is required from it. It can produce a calibrated outgoing
`CAR_POSE` only after the MCU has accepted `0x83`; this still does not block a
local lap when Pi data is absent.

## Field Test

1. Flash the current `LineFollowMissionDebug` image and leave the car stopped.
2. Confirm the ground station receives a fresh uncalibrated `CAR_POSE`
   (`CALIBRATED=0, CalibrationId=0`) and a current `FLIGHT_TELEMETRY` in IDLE.
3. Run the dry run first:

```bat
cd /d "F:\keil5\stm\ZET6 HAl\lidar_car"
powershell -NoProfile -ExecutionPolicy Bypass -File scripts\test_line_follow_calibration_link.ps1 -WirelessPort COMx -DiagPort COMy
```

4. With the car still stationary and raw Pi pose available, record the last
   uncalibrated outgoing X/Y. The script waits for `CAR_POSE.Seq mod 5 = 2`,
   delays 35 ms, then sends `0x83` inside the required maintenance window:

```bat
powershell -NoProfile -ExecutionPolicy Bypass -File scripts\test_line_follow_calibration_link.ps1 -WirelessPort COMx -DiagPort COMy -Send
```

5. `WirelessPort` is the ground-side LoRa serial port and `DiagPort` is the
   MCU diagnostic serial port; they must be different. Use `-DiagPort ""` if
   the diagnostic port is unavailable. The script creates its own `logs`
   directory when needed.
6. Pass criteria: an accepted `0x83` ACK from `0x30 -> 0x40` without any Pi
   ACK, followed by at least three `0x80 CAR_POSE` frames with `CALIBRATED=1`
   and the requested CalibrationId. Relative to the recorded uncalibrated output,
   `X_after-X_before=DeltaX` and `Y_after-Y_before=DeltaY`. Raw Pi/radar
   diagnostic X/Y must remain unchanged by the transaction.
7. Query diagnostics and confirm `pg12_short_press_only=1`, `motors_enabled=0`,
   and `maint_broadcast_left=0`.
   Low-active short-press PG12; after the 50 ms debounce the MCU must log
   `maintenance_reset_local_applied,reason=PG12_SHORT_PRESS`, clear local
   calibration without contacting Pi, then emit exactly three `0x85` copies
   with the same ResetId, Seq, and payload while only the final two set
   `RETRANSMISSION`. Subsequent outgoing `0x80` frames return to
   `CALIBRATED=0, CalibrationId=0`.
8. After `maint_broadcast_left=0`, short-press PG12 once more and confirm a new
   ResetId. The ground station then sends a new `0x83` Seq and CalibrationId to
   apply the next offset. Do not press PG12 during motion or during the
   three-frame broadcast.
9. A later short press must increment `maint_reset_attempts` and
   `maint_reset_successes`, use a new ResetId after the previous broadcast has
   completed, and leave `maint_last_result=PG12_SHORT_PRESS`. The V2.3
   Appendix physical-button timing is not implemented by this firmware and
   remains separate from the missing Pi reset ACK chain.

### Recalibration Debug

With the car stopped, a second `0x83` may replace the current MCU-local
calibration without PG12. Supply a new request sequence so the 5 s duplicate
cache does not replay the old ACK. The new `DeltaX/DeltaY` is absolute relative
to raw Pi output; a changed offset should use a new `CalibrationId`. For an
exact before/after delta assertion, provide the old complete offsets to the
test script:

```bat
powershell -NoProfile -ExecutionPolicy Bypass -File scripts\test_line_follow_calibration_link.ps1 -WirelessPort COMx -DiagPort COMy -DeltaXCm <newX> -DeltaYCm <newY> -PreviousDeltaXCm <oldX> -PreviousDeltaYCm <oldY> -CalibrationId <newId> -Sequence <newSeq> -AllowRecalibration -Send
```

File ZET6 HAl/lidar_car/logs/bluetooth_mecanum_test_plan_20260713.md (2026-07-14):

# Bluetooth Mecanum Direction Test

## UART

- Bluetooth: USART3 full remap, PD8 TX, PD9 RX, default 9600 baud.
- Diagnostic log: USART1 default, PA9 TX, PA10 RX, 115200 baud, routed to
  J-Link OB CDC COM port.

## Current command map

| Phone signal | Requested motion | LF | RF | LR | RR |
| --- | --- | ---: | ---: | ---: | ---: |
| `F` | Forward | +18 | +18 | +18 | +18 |
| `B` | Backward | -18 | -18 | -18 | -18 |
| `L` | Turn left | +8 | +18 | +8 | +18 |
| `R` | Turn right | +18 | +8 | +18 | +8 |
| `Q` | Rotate left | -18 | +18 | -18 | +18 |
| `E` | Rotate right | +18 | -18 | +18 | -18 |
| `S` or `0` | Stop | 0 | 0 | 0 | 0 |

The phone's confirmed aliases are `G=F`, `H=L`, `J=R`, `K=B`, and `I=S`.

After every power-up, press `I`/OK once to arm movement. Until then all motion
commands are logged but ignored. The motor build sends no READY or ACK strings
back to the Bluetooth module, preventing UART echo from becoming commands.

Unknown signals are logged and force a stop. Motion also stops after 800 ms
without another recognized motion signal. The current build has
`BLUETOOTH_MOTOR_OUTPUT_ENABLE=0`, so all motor commands are preview-only and
the four motors remain stopped.

## Verified physical positive direction

- LF forward: PE2=0, PE3=1, PWM PA2/TIM2_CH3.
- RF forward: PE4=1, PE5=0, PWM PA3/TIM2_CH4.
- LR forward after assembled-vehicle verification: PC6=1, PG1=0, PWM PA6.
- RR forward after assembled-vehicle verification: PE9=0, PE7=1, PWM PA7.

## Test procedure

1. Lift the chassis so all four wheels can rotate freely.
2. Open the J-Link CDC COM port at 115200 8N1.
3. Reset the STM32 and confirm `BT_MOTOR_READY`.
4. Confirm the boot line contains `output_enabled=0`.
5. Press one phone button once.
6. Save the resulting `BT_RX` and `MOTOR_PREVIEW` lines. The phone should also
   receive `ACK,<signal>` for recognized ASCII commands or `UNKNOWN,<signal>`.
7. Send the captured button-to-byte mapping for the next motor-enabled build.

Example expected log for phone signal `F`:

```text
BT_RX,1234,B,0x46,F
MOTOR_PREVIEW,1234,F,35,35,35,35
```

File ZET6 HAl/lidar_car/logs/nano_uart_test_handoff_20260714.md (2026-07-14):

# Jetson Nano UART5 Test Handoff

## Scope and safety

- Test layer: UART transport, text protocol, and diagnostic logging only.
- STM32 target: STM32F103ZET6.
- Nano UART: UART5, `PC12=MCU TX`, `PD2=MCU RX`, `115200 8N1`.
- PC diagnostic UART: USART1 remap, `PB6=MCU TX`, `PB7=MCU RX`, `115200 8N1`.
- `MotorSafe_InitOff()` runs before both UARTs and `MotorSafe_ForceOff()` runs continuously.
- UART4 sends the existing `#000PDST!` through `#005PDST!` stop commands once at boot.
- UART commands do not contain any motor or servo command.
- Use 3.3 V TTL only. Connect grounds. Do not connect either board's 5 V supply pin.
- Keep motor-driver and servo power disconnected during the first transport-only test.

## Preparation status checked on 2026-07-14

- STM32 Debug and Release builds both complete without compiler warnings.
- Debug HEX SHA256: `96E71B7EB08AAB32987E2D2CA5ABD666DFBDE8E1CD7487553FEB678384DEEBB4`.
- Release HEX SHA256: `01FA56EBAF74719131938B58C33B60E9419A4561E1F51BB36493A85BA53C27B8`.
- Nano is Python `3.6.9`; pyserial `3.5` is installed; user `nano` is in `dialout`.
- No USB-TTL endpoint was enumerated during inspection.
- `/dev/ttyTHS1` is owned by active/enabled `nvgetty`.
- The local Nano script passes Python 3.6 grammar validation.
- Final SSH rechecks timed out, so the script is prepared locally but not yet
  confirmed or copied at `/home/nano/yolov5/nano_uart_link_test.py`.

## Recommended physical path: USB-TTL plugged into Nano

This path does not require changing Nano services.

```text
STM32 PC12 / UART5 TX -> USB-TTL RX
STM32 PD2  / UART5 RX <- USB-TTL TX
STM32 GND              <-> USB-TTL GND
USB-TTL USB            -> Jetson Nano USB port
```

After insertion, use the stable `/dev/serial/by-id/...` name. Do not permanently
store `/dev/ttyUSB0`, because the number may change after replugging.

## Alternate path: Nano J41 direct UART

```text
Nano J41 pin 8  TX -> STM32 PD2 / UART5 RX
Nano J41 pin 10 RX <- STM32 PC12 / UART5 TX
Nano J41 pin 6 GND <-> STM32 GND
```

Current inspection found `/dev/ttyTHS1` occupied by `nvgetty`. Do not use this
path until `nvgetty` has been deliberately stopped/disabled for the test.
`/dev/ttyS0` is a kernel console and must not be used.

## PC diagnostic USB-TTL wiring

```text
STM32 PB6 / USART1 TX -> PC USB-TTL RX
STM32 PB7 / USART1 RX <- PC USB-TTL TX
STM32 GND              <-> PC USB-TTL GND
```

In adapter-centric wording, the adapter TX wire goes to PB7 and the adapter RX
wire goes to PB6.

## Build and flash

Prepared outputs:

```text
build/Debug/lidar_car.elf
build/Debug/lidar_car.hex
build/Debug/lidar_car.bin
build/Release/lidar_car.elf
build/Release/lidar_car.hex
build/Release/lidar_car.bin
```

Do not flash `build/BluetoothMotorDebug/lidar_car.hex`; it belongs to the older
Bluetooth motor test. The dedicated wrapper below always selects Debug.

Build, flash, verify sections, reset, and run with J-Link:

```powershell
.\scripts\jlink_flash_nano_uart.ps1
```

The expected PC diagnostic boot line is:

```text
BOOT,nano_uart_test,nano_baud=115200,diag_baud=115200,nano_pins=PC12_PD2,bluetooth_pins=PD8_PD9,diag_pins=PB6_PB7,motors_safe=1,servo_stop_sent=1
```

The same safe firmware also monitors JDY-3X on USART3 full remap `PD8/PD9` at
`9600 8N1`. It logs `BT_RX`, decoded `BT_KEY`, and periodic `BT_STAT` lines;
`BLUETOOTH_MOTOR_OUTPUT_ENABLE=0` is enforced by the build definition.

The Nano UART receives this initial line after every reset:

```text
STM32_READY,nano_uart_test,115200,motors_safe=1
```

It also receives an independent one-second marker, even if Nano TX is broken:

```text
HEARTBEAT,<uptime_ms>,rx_bytes=<count>,motors_safe=1
```

## Nano preparation and run

The prepared Python 3.6-compatible script is:

```text
yolov5/nano_uart_link_test.py
```

Copy it to `/home/nano/yolov5/nano_uart_link_test.py`, then list endpoints:

```bash
python3 /home/nano/yolov5/nano_uart_link_test.py --list
```

Run a 60-second PING/ECHO/VISION protocol check with the stable device name:

```bash
cd /home/nano/yolov5
python3 nano_uart_link_test.py \
  --port /dev/serial/by-id/REPLACE_WITH_ACTUAL_DEVICE \
  --duration 60 \
  --vision-test \
  --log nano_uart_link_20260714.csv
```

Only after the low-rate test passes, run the transport stress stage with no
motor/servo power:

```bash
python3 nano_uart_link_test.py \
  --port /dev/serial/by-id/REPLACE_WITH_ACTUAL_DEVICE \
  --duration 60 \
  --vision-rate 30 \
  --log nano_uart_vision30_20260714.csv
```

## PC diagnostic capture

List COM ports if the port is unknown:

```powershell
.\scripts\capture_nano_uart_diag.ps1
```

Capture a known port for 60 seconds:

```powershell
.\scripts\capture_nano_uart_diag.ps1 -PortName COM16 -Seconds 60
```

Freeze and export the 128-event RAM ring after a test:

```powershell
.\scripts\capture_nano_uart_diag.ps1 -PortName COM16 -Seconds 20 -Command E
```

## Protocol

```text
Nano -> STM32: PING,<seq>\n
STM32 -> Nano: PONG,<seq>,<uptime_ms>\r\n

Nano -> STM32: ECHO,<payload>\n
STM32 -> Nano: ECHO_ACK,<payload>\r\n

Nano -> STM32: VISION,<seq>,<class>,<confidence>,<x1>,<y1>,<x2>,<y2>\n
STM32 -> Nano: VISION_ACK,<seq>\r\n

Nano -> STM32: STATUS\n
STM32 -> Nano: STATUS,<uptime_ms>,rx_bytes=...,rx_lines=...,parse_err=...,motors_safe=1\r\n
```

## Diagnostic log fields

```text
BOOT,...
NANO_RX_LINE,<time_ms>,<line>
NANO_TX,<time_ms>,<line>
NANO_STAT,<time_ms>,rx_bytes=...,rx_lines=...,tx_lines=...,parse_err=...,overflow=...,motors_safe=1
FAULT,<time_ms>,<reason>
```

`NANO_STAT` also separates parity, framing, noise, and overrun errors and reports
`last_rx_age_ms`. The most recent 128 protocol/error events are retained in RAM.
From the PC diagnostic adapter send `F` to freeze, `E`/`D` to freeze and export,
or `C` to clear and resume the event ring.

Per-byte logging exists behind `NANO_UART_TRACE_BYTES=1`, but remains disabled by
default because blocking byte logs can disturb high-rate UART reception.

## Pass gates

1. `STM32_READY` is received after reset.
2. At least 60 PINGs produce matching PONG sequence values.
3. PONG success rate is 100% for the isolated one-minute test.
4. ECHO payloads match exactly.
5. Synthetic VISION lines receive matching `VISION_ACK` values.
6. STM32 diagnostic `parse_err=0` and `overflow=0`.
7. `uart_pe=0`, `uart_fe=0`, `uart_ne=0`, and `uart_ore=0`.
8. `motors_safe=1` remains present and no wheel or servo moves.

## Staged order imported from the radar-car wireless history

1. W0: logic power only; verify BOOT/STM32_READY/HEARTBEAT and exact 115200 8N1.
2. W1: low-rate PING/ECHO; verify byte/line counts and zero UART hardware errors.
3. W2: test LF, CRLF, empty ECHO payload, comma payload, malformed command, and
   overlength recovery; export the event ring afterward.
4. W3: motor/servo power still off; run synthetic VISION at 30 Hz for 60 seconds.
5. W4: connect the real YOLO output, still ACK/log only and still no motor command.

Do not enter a later stage when the earlier stage has parse, overrun, endpoint,
or wiring errors. This preserves the historical “raw link before business logic”
gate and prevents a serial fault from being misdiagnosed as a vision/control bug.

## Stop conditions

- Any wheel or servo moves: remove motor power immediately and inspect the flashed image/tag.
- Garbled bytes: verify `115200 8N1`, crossed TX/RX, shared ground, and 3.3 V levels.
- No device under `/dev/serial/by-id`: USB-TTL is not enumerated; do not guess a tty name.
- Direct J41 path cannot open `/dev/ttyTHS1`: confirm `nvgetty` ownership before changing code.

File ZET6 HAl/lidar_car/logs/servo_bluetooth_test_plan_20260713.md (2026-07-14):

# Servo and Bluetooth Test Plan

## Frozen baseline

- Four-wheel direction checkpoint: `55366cd`.
- This firmware must not initialize or drive the TT motor PWM paths.
- All TT motor enable, standby, and direction outputs are forced low in the main loop.

## UART allocation

| Link | Peripheral | TX | RX | Baud |
| --- | --- | --- | --- | --- |
| Diagnostic log | USART1 remap | PB6 | PB7 | 115200 |
| ZL bus servo | UART4 | PC10 | PC11 | 115200 |
| Bluetooth | USART3 full remap | PD8 | PD9 | 9600 default |
| Jetson Nano | UART5 | PC12 | PD2 | 115200 |

Bluetooth baud can be changed at build time with `BLUETOOTH_BAUDRATE`.

## Servo pose table

| ID | Joint | Initial | Increasing value | Decreasing value | Calibration note |
| --- | --- | ---: | --- | --- | --- |
| S0 | Right yaw | 1700 | Outward | Inward | Observed offset about +200; command values remain authoritative |
| S1 | Right pitch | 1800 | Up | Down | Observed offset about +321 |
| S2 | Right end effector | 986 | Outward | Inward | Verify after assembly |
| S3 | Left yaw | 1600 | Outward | Inward | Verify after assembly |
| S4 | Left pitch | 1178 | Up | Down | Verify after assembly |
| S5 | Left end effector | 1400 | Outward | Inward | Verify after assembly |

| Pose | S0 | S1 | S2 | S3 | S4 | S5 |
| --- | ---: | ---: | ---: | ---: | ---: | ---: |
| INITIAL | 1700 | 1800 | 986 | 1600 | 1178 | 1400 |
| GRAB | 1550 | 1450 | 1020 | 1450 | 846 | 1485 |
| OPEN | 1650 | 1450 | 1020 | 1550 | 846 | 1485 |
| LIFT | 1520 | 1720 | 1020 | 1400 | 1100 | 1485 |
| LOWER | 1520 | 1700 | 1020 | 1400 | 1100 | 1485 |
| STACK | 1560 | 1700 | 1020 | 1450 | 1100 | 1485 |

Each move command currently uses 1500 ms. No pose is sent automatically at boot.

## Command table

Commands may be entered through Bluetooth or the diagnostic UART RX pin.

| Command | Action |
| --- | --- |
| `I` or `0` | Initial pose |
| `G` or `1` | Grab pose |
| `O` or `2` | Open pose |
| `U` or `3` | Lift pose |
| `D` or `4` | Lower pose |
| `K` or `5` | Stack pose |
| `S` | Send stop command to IDs 0-5 |
| `R` | Release torque for IDs 0-5 |
| `Q` | Query angle for IDs 0-5 |
| `H` or `?` | Print help |

## First hardware test order

1. Disconnect or lift the chassis so wheel motion cannot translate the robot.
2. Connect common ground between STM32, servo controller, Bluetooth, and their supplies.
3. Power the servos from the specified external servo supply, not from the MCU 3.3 V rail.
4. Open the PB6/PB7 diagnostic link at 115200 8N1.
5. Reset the STM32 and confirm `motors_safe=1` and `automatic_motion=0`.
6. Send `H` through Bluetooth and verify both `CMD_RX` in the diagnostic log and `ACK,H` on Bluetooth.
7. Send `Q` and verify that responses are recorded as `SERVO_RX`.
8. With the mechanism unloaded, send `I` and verify S0-S5 one at a time against the table.
9. Test `G`, `O`, `U`, `D`, and `K` individually. Do not run an automatic sequence until every row is marked pass.
10. Save the terminal capture and complete the CSV template.

## Required observations

- Confirm each physical servo ID matches S0-S5.
- Record whether increasing position moves in the documented direction.
- Record any binding, excessive current, controller reset, missing response, or unexpected wheel output.
- If any axis direction or limit is wrong, stop and update only that pose/axis after preserving this build.

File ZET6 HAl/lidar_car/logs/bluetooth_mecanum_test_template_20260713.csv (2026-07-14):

run_id | phone_button | rx_hex | rx_ascii | requested_motion | lf_actual | rf_actual | lr_actual | rr_actual | timeout_stop | pass | notes
1 | forward | N/A | N/A | forward | N/A | N/A | N/A | N/A | N/A | N/A

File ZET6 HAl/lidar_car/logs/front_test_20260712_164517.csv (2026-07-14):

# actual_behavior: LF forward once; RF intermittent forward twice
# expected_order: LF_POS | LF_NEG | RF_POS | RF_NEG; rear OFF
seq | time_ms | event | wheel | cmd | pe_odr | pc_odr | tim5_ccr1 | tim5_ccr2 | tim3_ccr1 | tim3_ccr2
0 | 0 | 2 | 255 | 0 | 0x0000 | 0x0000 | 0 | 0 | 0 | 0
1 | 0 | 1 | 255 | 0 | 0x0000 | 0x0000 | 0 | 0 | 0 | 0
2 | 1000 | 3 | 0 | 60 | 0x0400 | 0x0000 | 2160 | 0 | 0 | 0
3 | 2500 | 4 | 0 | 0 | 0x0000 | 0x0000 | 0 | 0 | 0 | 0
4 | 3500 | 3 | 0 | -60 | 0x0800 | 0x0000 | 2160 | 0 | 0 | 0
5 | 5000 | 4 | 0 | 0 | 0x0000 | 0x0000 | 0 | 0 | 0 | 0
6 | 7000 | 3 | 1 | 60 | 0x1000 | 0x0000 | 0 | 2160 | 0 | 0
7 | 8500 | 4 | 1 | 0 | 0x0000 | 0x0000 | 0 | 0 | 0 | 0
8 | 9500 | 3 | 1 | -60 | 0x0000 | 0x0080 | 0 | 2160 | 0 | 0
9 | 11000 | 4 | 1 | 0 | 0x0000 | 0x0000 | 0 | 0 | 0 | 0
10 | 13000 | 1 | 255 | 0 | 0x0000 | 0x0000 | 0 | 0 | 0 | 0

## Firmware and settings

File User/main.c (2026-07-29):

#include "stm32f10x.h"
#include "Delay.h"
#include "OLED.h"
#include "bsp_usart.h"
#include "bsp_key.h"
#include "bsp_key2.h"
#include "bsp_systick.h"
#include "bsp_led_pwm.h"
#include "bsp_buzzer.h"
#include "app_motor.h"
#include "bsp_ir_gpio.h"
#include "HCSR04.h"
#include <stdio.h>

/*====================================================================================*/
/*                          GPIO 循迹 + 高频闭环 (V7)                                  */
/*====================================================================================*/
/*
 * GPIO 直接读取循迹 (< 1μs vs I2C 500μs)
 * 控制周期 2ms (500Hz)
 * 非线性Kp + 弯道自动减速
 * 速度PI闭环 + 循迹PD外环
 */

/*====================================================================================*/
/*====================================================================================*/
/*                    【干净版】速度PI闭环 + 循迹PD                                   */
/*====================================================================================*/
/*
 * 调参顺序：
 * 
 * 【第一步】速度环（内环）：先P后I，不要D
 *   1. Ki=0，从Kp=0.01开始翻倍，直到电机能转
 *   2. 继续增加Kp，直到出现"嗡嗡"震动，记录此值
 *   3. 取50%作为最终Kp
 *   4. 加Ki（通常是Kp的1/10~1/100），消除静差
 * 
 * 【第二步】循迹环（外环）：先P后D
 *   1. Kd=0，从小到大调Kp，直到出现明显波动
 *   2. 取50%~60%作为最终Kp
 *   3. 加Kd抑制振荡，让过弯更丝滑
 */

/*==================== 速度环参数（内环）====================*/
/* MG310 电机动力很强，PWM=30 就能跑 650mm/s
 * Kp=0.18/Ki=0.12 在500mm/s时OK但320mm/s时PWM振荡(0~33跳动)
 * Kp=0.12/Ki=0.04 不振荡但太慢：目标364实际220，差速建立不起来
 * 折中：Kp=0.15/Ki=0.06，兼顾平滑与响应
 */
#define SPEED_KP            0.15f       /* 速度P - 折中值 */
#define SPEED_KI            0.08f       /* 速度I - 竞速提高：更快跟踪高目标速度 */
#define INTEGRAL_MAX        200.0f      /* 积分限幅 - 竞速放宽：高速需更大积分空间 */

/*==================== 循迹环参数（外环）====================*/
/* 调试步骤：
 * 1. 先设 Kd=0，从小到大调 Kp
 * 2. Kp 太小：转弯迟钝，跟不上线
 * 3. Kp 太大：左右摆动（蛇形）
 * 4. 找到临界点后，加 Kd 抑制摆动
 */
#define TRACK_KP            12.00f       /* 循迹P - 竞速650：高速需更强响应 */
#define TRACK_KD            2.50f        /* 循迹D - 竞速650：高速需更强阻尼 */

/*==================== 速度设定 ====================*/
/* 注意：PWM=30 对应约 650 mm/s
 * 基础速度要根据实际电机能力设置
 */
#define BASE_SPEED_MMS      650.0f      /* 竞速模式 650mm/s */
#define MIN_SPEED_MMS        60.0f      /* 最低速度 mm/s */
#define MAX_SPEED_MMS       1100.0f     /* 提高上限：650+400(turnOut)=1050 */

/*==================== PWM限制 ====================*/
/* 注意：电机驱动接受 0~100 的百分比值
 * PWM_MAX 设太低会导致 Kp 调不出震动（输出被限幅）
 * 建议设为 80~100，给 PI 足够的调节空间
 */
#define PWM_MAX             100.0f
#define PWM_MIN             0.0f

/*==================== 滤波参数 ====================*/
#define SPEED_FILT_ALPHA    0.3f        /* 速度滤波 - 增大减少滞后 */

/*==================== 辅助宏 ====================*/
#define ABSF(x)             (((x) >= 0.0f) ? (x) : -(x))

#define DISPLAY_PAGES       2

/*==================== 日志缓冲系统 ====================*/
/* 运行时存到RAM，停下来后通过串口导出
 * 每条日志 8 字节，可存约 2000 条（约 20 秒 @ 10ms周期）
 */
#define LOG_ENABLE          1           /* 1=启用日志，0=关闭 */
#define LOG_PERIOD_MS       10          /* 日志记录周期（ms）*/
#define LOG_MAX_ENTRIES     1400        /* 最大日志条数（扩展诊断字段后降低容量以控RAM） */

typedef struct {
    uint16_t timeMs;        /* 相对时间（ms） */
    uint16_t seq;           /* 行序号（导出完整性校验） */
    uint8_t  testId;        /* 每行都带测试编号，避免分片时丢上下文 */

    int8_t   trackError;    /* 循迹误差 */
    uint8_t  sensorRaw;     /* 传感器原始值 */
    int8_t   pwmL;          /* 左轮PWM */
    int8_t   pwmR;          /* 右轮PWM */
    int8_t   speedL;        /* 左轮速度/10（实际=值*10 mm/s） */
    int8_t   speedR;        /* 右轮速度/10 */
    int16_t  tgtL;          /* 目标左轮速度 mm/s */
    int16_t  tgtR;          /* 目标右轮速度 mm/s */

    uint8_t  flags;         /* bit0:edgeTurn, bit1:edgeL, bit2:edgeR,
                               bit3:recovery, bit4:protection,
                               bit5:postEtLock, bit6:kpBoost, bit7:stabilize */
    uint8_t  edgeTurnSlow;  /* 边缘退出缓行剩余帧 */
    uint8_t  satInfo;       /* bit0:turnSat, bit1:pwmLsat, bit2:pwmRsat */
    int8_t   kpScale10;     /* 动态Kp倍率*10（10=1.0x） */
    int8_t   dtMs;          /* 控制周期ms */
    int8_t   errSpdL10;     /* (tgtL-speedL)/10 */
    int8_t   errSpdR10;     /* (tgtR-speedR)/10 */

    int16_t  turnOutput;    /* 转向输出（合成后） */
    int16_t  dynBaseSpd;    /* 动态基础速度 mm/s */
} LogEntry_t;

#if LOG_ENABLE
static LogEntry_t s_logBuffer[LOG_MAX_ENTRIES];
static uint16_t s_logIndex = 0;
static uint16_t s_logSeq = 0;
static uint32_t s_logStartMs = 0;
static uint32_t s_lastLogMs = 0;
static uint8_t s_logRunning = 0;
static uint8_t s_testNum = 0;          /* 当前测试编号（1,2,3...） */

/* 添加一条日志 */
static void Log_Add(uint32_t nowMs, int8_t err, uint8_t raw,
                    float pwmL, float pwmR, float spdL, float spdR,
                    float tgtL, float tgtR,
                    uint8_t flags, uint8_t etSlow,
                    uint8_t satInfo, float kpScale, float dtMs,
                    float errSpdL, float errSpdR,
                    float turnOut, float dynBase)
{
    if (s_logIndex >= LOG_MAX_ENTRIES) return;

    LogEntry_t *entry = &s_logBuffer[s_logIndex];
    float kp10 = kpScale * 10.0f;
    float eL10 = errSpdL / 10.0f;
    float eR10 = errSpdR / 10.0f;
    entry->timeMs = (uint16_t)(nowMs - s_logStartMs);
    entry->seq = s_logSeq++;
    entry->testId = s_testNum;
    entry->trackError = err;
    entry->sensorRaw = raw;
    entry->pwmL = (int8_t)pwmL;
    entry->pwmR = (int8_t)pwmR;
    entry->speedL = (int8_t)(spdL / 10.0f);
    entry->speedR = (int8_t)(spdR / 10.0f);
    entry->tgtL = (int16_t)tgtL;
    entry->tgtR = (int16_t)tgtR;
    entry->flags = flags;
    entry->edgeTurnSlow = etSlow;
    entry->satInfo = satInfo;
    if (kp10 > 127.0f) kp10 = 127.0f;
    if (kp10 < -128.0f) kp10 = -128.0f;
    entry->kpScale10 = (int8_t)kp10;
    if (dtMs > 127.0f) dtMs = 127.0f;
    if (dtMs < -128.0f) dtMs = -128.0f;
    entry->dtMs = (int8_t)dtMs;
    if (eL10 > 127.0f) eL10 = 127.0f;
    if (eL10 < -128.0f) eL10 = -128.0f;
    if (eR10 > 127.0f) eR10 = 127.0f;
    if (eR10 < -128.0f) eR10 = -128.0f;
    entry->errSpdL10 = (int8_t)eL10;
    entry->errSpdR10 = (int8_t)eR10;
    entry->turnOutput = (int16_t)turnOut;
    entry->dynBaseSpd = (int16_t)dynBase;
    s_logIndex++;
}

/* 插入测试分隔标记：trackError=127 表示这是一个标记条目，testNum存在sensorRaw中 */
static void Log_InsertTestMarker(uint32_t nowMs)
{
    if (s_logIndex >= LOG_MAX_ENTRIES) return;
    LogEntry_t *entry = &s_logBuffer[s_logIndex];
    entry->timeMs = 0;
    entry->seq = s_logSeq++;
    entry->testId = s_testNum;
    entry->trackError = 127;        /* 特殊标记值，正常范围不会出现 */
    entry->sensorRaw = s_testNum;   /* 测试编号 */
    entry->pwmL = 0;
    entry->pwmR = 0;
    entry->speedL = 0;
    entry->speedR = 0;
    entry->tgtL = 0;
    entry->tgtR = 0;
    entry->flags = 0xFF;            /* 全1标志，便于识别 */
    entry->edgeTurnSlow = 0;
    entry->satInfo = 0;
    entry->kpScale10 = 10;
    entry->dtMs = 0;
    entry->errSpdL10 = 0;
    entry->errSpdR10 = 0;
    entry->turnOutput = 0;
    entry->dynBaseSpd = 0;
    s_logIndex++;
}

/* 开始记录（追加模式：不清空缓冲区，插入测试标记） */
static void Log_Start(uint32_t nowMs)
{
    s_testNum++;
    Log_InsertTestMarker(nowMs);
    s_logStartMs = nowMs;
    s_lastLogMs = nowMs;
    s_logRunning = 1;
}

/* 停止记录 */
static void Log_Stop(void)
{
    s_logRunning = 0;
}

/* 清空日志缓冲区 */
static void Log_Clear(void)
{
    s_logIndex = 0;
    s_logSeq = 0;
    s_testNum = 0;
    s_logRunning = 0;
}

/* 统计8位中1的个数（active触发点数） */
static uint8_t PopCount8(uint8_t x)
{
    uint8_t c = 0;
    while (x) {
        c += (uint8_t)(x & 1U);
        x >>= 1;
    }
    return c;
}

/* 导出日志到串口（CSV格式，改进版：每行延时防截断，测试标记分隔）*/
static void Log_Export(void)
{
    char buf[180];
    uint16_t i;

    /* 使用 UART4 (PC10/PC11) - DAPLink 连接到这里 */
    UART4_init(115200);
    Delay_ms(50);

    /* 导出标记 */
    sprintf(buf, "#LOG_BEGIN,%u,%u\r\n", s_logIndex, s_testNum);
    UART4_Send_String(buf);
    Delay_ms(5);

    /* 打印表头 */
    UART4_Send_String("seq,test_id,time_ms,error,sensor,active,cnt,pwmL,pwmR,speedL,speedR,tgtL,tgtR,flags,etSlow,sat,kpScale10,dtMs,errSpdL10,errSpdR10,turnOut,dynBase\r\n");
    Delay_ms(5);

    /* 打印数据 */
    for (i = 0; i < s_logIndex; i++) {
        LogEntry_t *e = &s_logBuffer[i];

        /* 测试分隔标记：trackError==127 && flags==0xFF */
        if (e->trackError == 127 && e->flags == 0xFF) {
            sprintf(buf, "#TEST,%u\r\n", e->sensorRaw);
            UART4_Send_String(buf);
            Delay_ms(3);
            continue;
        }

        {
            uint8_t active = (uint8_t)(~e->sensorRaw);
            uint8_t cnt = PopCount8(active);
            sprintf(buf, "%u,%u,%u,%d,0x%02X,0x%02X,%u,%d,%d,%d,%d,%d,%d,0x%02X,%u,0x%02X,%d,%d,%d,%d,%d,%d\r\n",
                    (unsigned)e->seq,
                    (unsigned)e->testId,
                    (unsigned)e->timeMs,
                    e->trackError,
                    e->sensorRaw,
                    active,
                    cnt,
                    e->pwmL,
                    e->pwmR,
                    e->speedL * 10,
                    e->speedR * 10,
                    (int)e->tgtL,
                    (int)e->tgtR,
                    e->flags,
                    e->edgeTurnSlow,
                    e->satInfo,
                    e->kpScale10,
                    e->dtMs,
                    e->errSpdL10,
                    e->errSpdR10,
                    (int)e->turnOutput,
                    (int)e->dynBaseSpd);
            UART4_Send_String(buf);
        }

        /* 每行加2ms延时，降低串口拥塞导致的拼行风险 */
        Delay_ms(2);
    }

    sprintf(buf, "# Total: %u entries, %u tests\r\n", s_logIndex, s_testNum);
    UART4_Send_String(buf);
    UART4_Send_String("#LOG_END\r\n");
}
#endif /* LOG_ENABLE */

/* 传感器权重 - 非线性分布（1,3,9,27模式）
 * 边缘传感器权重更大，让弯道反应更激烈
 * 线在左边 → 误差为负 → 左轮减速
 * 线在右边 → 误差为正 → 右轮减速
 */
static const int8_t SENSOR_WEIGHTS_V5[8] = {
    -12,    /* X1: 最左边 - 超大权重！ */
    -8,    /* X2 */
    -3,    /* X3 */
    -1,     /* X4: 中心左 */
    1,      /* X5: 中心右 */
    3,     /* X6 */
    8,     /* X7 */
    12      /* X8: 最右边 - 超大权重！ */
};

/*==================== 速度PI结构体 ====================*/
typedef struct {
    float Kp, Ki;
    float integral;
    float integralMax;
    float outMin, outMax;
} PI_t;

static PI_t s_piL, s_piR;           /* 左右轮速度PI */
static float s_pwmL = 0, s_pwmR = 0; /* 当前PWM */
static float s_speedL_f = 0, s_speedR_f = 0;  /* 滤波后速度 */
static uint8_t s_speedFiltInit = 0;  /* 速度滤波初始化标志 */
static int8_t s_lastDir = 1;         /* 上次方向：1=右，-1=左 */
static uint8_t s_dirConfident = 0;   /* 方向置信度：1=来自|err|>=3的深弯，0=来自|err|<3的浅偏 */
static int8_t s_lastErr = 0;         /* 上次误差（显示用） */
static uint32_t s_runStartMs = 0;    /* 本次运行启动时刻 */
static uint16_t s_finishVoteCnt = 0; /* 终点检测：连续全触发帧计数 */

/*==================== 超声波避障 ====================*/
/*
 * 40cm 预警(不干涉), 20cm 介入(接管), 30cm 退出(迟滞)
 * 梯度法: 下次距离 > 上次 → 方向正确; 反之翻转
 * 有线时仅降速, 无线时转向避障
 */
#define OBS_PERIOD_MS       60      /* 测量周期 ms */
#define OBS_WARN_CM         40.0f
#define OBS_AVOID_CM        20.0f
#define OBS_EXIT_CM         30.0f   /* 退出迟滞 */
#define OBS_SPEED_FLOOR     0.25f   /* 最低速度比 */
#define OBS_TURN_BASE       180.0f  /* 避障基础转向 */
#define OBS_FILT_ALPHA      0.4f    /* 距离一阶滤波 */
#define OBS_DIR_DEADBAND    1.0f    /* 梯度翻转死区 cm */
#define OBS_DIR_LOCK_CNT    2       /* 翻转后锁定次数 */

typedef enum { OBS_NONE = 0, OBS_WARNING, OBS_AVOID } ObsState_t;

static ObsState_t s_obsState      = OBS_NONE;
static float      s_obsDist       = -1.0f;   /* 滤波后距离 */
static float      s_obsPrevDist   = -1.0f;   /* 上次距离(梯度用) */
static int8_t     s_obsTurnDir    = 0;        /* +1 右转, -1 左转 */
static uint8_t    s_obsDirLock    = 0;        /* 方向锁定倒计数 */
static uint32_t   s_lastUltrasonicMs = 0;

static void Obs_Reset(void)
{
    s_obsState    = OBS_NONE;
    s_obsDist     = -1.0f;
    s_obsPrevDist = -1.0f;
    s_obsTurnDir  = 0;
    s_obsDirLock  = 0;
}

/*==================== PI函数 ====================*/
static void PI_Init(PI_t *pi, float kp, float ki, float intMax, float outMin, float outMax)
{
    pi->Kp = kp;
    pi->Ki = ki;
    pi->integral = 0;
    pi->integralMax = intMax;
    pi->outMin = outMin;
    pi->outMax = outMax;
}

static float PI_Compute(PI_t *pi, float target, float actual)
{
    float err = target - actual;
    float out;

    /* 积分累加 - 注意：这里没有乘以dt，所以Ki要设得很小 */
    /* 控制周期是2ms，每秒累加500次 */
    pi->integral += err;

    /* 积分限幅 - 防止积分饱和！ */
    if (pi->integral > pi->integralMax) pi->integral = pi->integralMax;
    if (pi->integral < -pi->integralMax) pi->integral = -pi->integralMax;

    /* PI输出 */
    out = pi->Kp * err + pi->Ki * pi->integral;

    /* 输出限幅 */
    if (out > pi->outMax) out = pi->outMax;
    if (out < pi->outMin) out = pi->outMin;
    
    return out;
}

static void PI_Reset(PI_t *pi)
{
    pi->integral = 0;
}

int main(void)
{
    uint8_t ir_raw = 0xFF;
    uint32_t lastControlMs = 0;
    uint32_t lastOledMs = 0;
    char buf[24];
    KeyEvent_t keyEvent;
    Key2Event_t key2Event;
    uint8_t running = 0;
    uint8_t displayPage = 0;
    uint32_t c5PressStartMs = 0;
    uint8_t c5Pressing = 0;
    /* LED 亮度档位 (PWM周期=50, 值域0-50): 48/30/15/3 */
    static const uint8_t ledBrightTable[] = {48, 30, 15, 3};
    uint8_t ledBrightIdx = 0;
    uint32_t lastPeriphMs = 0;

    float speedL = 0, speedR = 0;
    float targetL = 0, targetR = 0;
    
    /* 初始化 */
    SysTick_Init();
    Key_Init();
    Key2_Init();
    
    /* GPIO 循迹初始化 */
    IR_GPIO_Init();

    /* 超声波初始化 */
    HCSR04_Init();
    
    /* OLED 初始化 */
    OLED_Init();

#if LOG_ENABLE
    /* 启动标记：用于验证PC10日志串口是否有输出 */
    UART4_init(115200);
    Delay_ms(10);
    UART4_Send_String("#BOOT\r\n");
#endif
    Delay_ms(100);

    /* LED PWM (TIM6 自驱动) + 蜂鸣器 */
    LED_PWM_Init();
    LED_Switch(LED_GREEN, 1);
    LED_Switch(LED_RED, 1);
    Buzzer_Init();

    /* 电机和编码器 */
    Set_Motor(0);
    Encoder_Init();
    Encoder_Reset();
    
    /* 速度 PI 初始化 */
    PI_Init(&s_piL, SPEED_KP, SPEED_KI, INTEGRAL_MAX, PWM_MIN, PWM_MAX);
    PI_Init(&s_piR, SPEED_KP, SPEED_KI, INTEGRAL_MAX, PWM_MIN, PWM_MAX);
    
    OLED_Clear();
    OLED_ShowString(1, 1, "V7 Track+Obs");
    OLED_ShowString(2, 1, "650mm/s GPIO");
    OLED_ShowString(3, 1, "C5L:Start/Stop");
    OLED_ShowString(4, 1, "C5S:Page C4:Stp");
    Buzzer_PlayBeep(BEEP_STARTUP);
    
    lastControlMs = SysTick_GetMs();
    lastOledMs = lastControlMs;
    s_lastUltrasonicMs = lastControlMs;
    lastPeriphMs = lastControlMs;

    while (1)
    {
        uint32_t nowMs = SysTick_GetMs();

        /* 按键扫描 — Key2 由 TIM1 ISR 每1ms扫描，此处仅读取事件 */
        keyEvent = Key_Scan();
        key2Event = Key2_GetEvent();
        if (key2Event != KEY2_EVENT_NONE) Key2_ClearEvent();

        /* C5 按压追踪 — running 时跳过 */
        if (!running) {
            if (Key_GetLevel() == 0) {
                if (!c5Pressing) { c5PressStartMs = nowMs; c5Pressing = 1; }
            } else {
                c5Pressing = 0;
            }
        }

        /* PC4 按键处理 */
        if (running) {
            /* 运行中: 任意按 = 紧急停止 */
            if (key2Event == KEY2_EVENT_SHORT || key2Event == KEY2_EVENT_LONG) {
                Motor_SetSpeedBoth(0, 0);
                running = 0;
                s_pwmL = 0; s_pwmR = 0;
                PI_Reset(&s_piL);
                PI_Reset(&s_piR);
                s_speedFiltInit = 0;
                Obs_Reset();
                TIM_Cmd(TIM6, ENABLE);
                LED_Switch(LED_GREEN, 1);
                LED_Switch(LED_RED, 1);
                Buzzer_PlayBeep(BEEP_KEY_PRESS);
#if LOG_ENABLE
                Log_Stop();
#endif
            }
        } else {
            /* 待机: 短按或长按都循环LED亮度档位 */
            if (key2Event == KEY2_EVENT_SHORT || key2Event == KEY2_EVENT_LONG) {
                ledBrightIdx = (ledBrightIdx + 1) % (sizeof(ledBrightTable)/sizeof(ledBrightTable[0]));
                LED_SetBrightness(LED_GREEN, ledBrightTable[ledBrightIdx]);
                LED_SetBrightness(LED_RED,   ledBrightTable[ledBrightIdx]);
            }
        }
        
        /* C5 短按=切页 (仅待机), C5 长按=启停 */
        if (keyEvent == KEY_EVENT_SHORT && !running) {
            displayPage = (displayPage + 1) % DISPLAY_PAGES;
            OLED_Clear();
        }
        if (keyEvent == KEY_EVENT_LONG) {
            running = running ? 0 : 1;
            if (running) {
                /* 启动 */
                Buzzer_PlayBeep(BEEP_ACTIVATE);
                LED_Switch(LED_GREEN, 0);
                LED_Switch(LED_RED, 0);
                LED_Switch(LED_INDICATOR, 0);
                TIM_Cmd(TIM6, DISABLE);
                s_piL.integral = 150.0f;
                s_piR.integral = 150.0f;
                s_speedFiltInit = 0;
                s_runStartMs = nowMs;
                s_finishVoteCnt = 0;
                Obs_Reset();
#if LOG_ENABLE
                Log_Start(nowMs);
#endif
            } else {
                /* 停止 */
                Motor_SetSpeedBoth(0, 0);
                s_pwmL = 0; s_pwmR = 0;
                PI_Reset(&s_piL);
                PI_Reset(&s_piR);
                s_speedFiltInit = 0;
                Obs_Reset();
                TIM_Cmd(TIM6, ENABLE);
                LED_Switch(LED_GREEN, 1);
                LED_Switch(LED_RED, 1);
                Buzzer_PlayBeep(BEEP_KEY_PRESS);
#if LOG_ENABLE
                Log_Stop();
#endif
            }
            s_lastErr = 0;
        }

        /* 低频外设更新 — running 100ms 仅蜂鸣器, 待机 20ms */
        {
            uint32_t periphInterval = running ? 100 : 20;
            if ((nowMs - lastPeriphMs) >= periphInterval) {
                Buzzer_Update(nowMs - lastPeriphMs);
                lastPeriphMs = nowMs;
            }
        }

        /* ===== 超声波非阻塞轮询 + 避障状态机 ===== */
        HCSR04_Poll();
        if ((nowMs - s_lastUltrasonicMs) >= OBS_PERIOD_MS) {
            s_lastUltrasonicMs = nowMs;
            HCSR04_StartMeasure();
        }
        if (running && HCSR04_IsNewReady()) {
            float rawDist = HCSR04_GetDistance();
            if (rawDist > 0.0f) {
                /* 一阶低通滤波 */
                if (s_obsDist < 0.0f) s_obsDist = rawDist;
                else s_obsDist += OBS_FILT_ALPHA * (rawDist - s_obsDist);

                /* --- 状态转换 --- */
                if (s_obsDist < OBS_AVOID_CM) {
                    if (s_obsState != OBS_AVOID) {
                        /* 首次进入避障: 初始方向取循迹方向 */
                        s_obsTurnDir = s_lastDir;
                        s_obsDirLock = OBS_DIR_LOCK_CNT;
                        s_obsState = OBS_AVOID;
                    } else if (s_obsDirLock > 0) {
                        s_obsDirLock--;  /* 刚翻转，锁定等稳定 */
                    } else if (s_obsPrevDist > 0.0f) {
                        /* 梯度判断: 越来越近 → 方向错了，翻转 */
                        if (s_obsDist < s_obsPrevDist - OBS_DIR_DEADBAND) {
                            s_obsTurnDir = -s_obsTurnDir;
                            s_obsDirLock = OBS_DIR_LOCK_CNT;
                        }
                        /* 越来越远或不变 → 保持 */
                    }
                } else if (s_obsState == OBS_AVOID) {
                    if (s_obsDist >= OBS_EXIT_CM) {
                        /* 退出避障: 设搜索方向为避障反方向（线在那一侧） */
                        s_lastDir = -s_obsTurnDir;
                        s_dirConfident = 1;
                        s_obsState = OBS_NONE;
                    }
                    /* 20~30cm 迟滞区: 保持避障 */
                } else if (s_obsDist < OBS_WARN_CM) {
                    s_obsState = OBS_WARNING;
                } else {
                    s_obsState = OBS_NONE;
                }
                s_obsPrevDist = s_obsDist;
            }
            /* 测量失败(-1): 保持当前状态 */
        }

        /* 编码器更新 + 控制周期 2ms（高频控制，快速响应）
         * 500mm/s 下每2ms移动1mm，必须快速反应
         */
        if ((nowMs - lastControlMs) >= 2)
        {
            float dt = (float)(nowMs - lastControlMs) / 1000.0f;
            if (dt < 0.002f) dt = 0.002f;
            
            /* 第一时间读取传感器！不要等！ */
            ir_raw = IR_GPIO_Read();
            
            /* 更新编码器 */
            Encoder_Update(nowMs - lastControlMs);
            speedL = Encoder_GetSpeedMMS(ENCODER_LEFT);
            speedR = Encoder_GetSpeedMMS(ENCODER_RIGHT);

            if (!s_speedFiltInit) {
                s_speedL_f = speedL;
                s_speedR_f = speedR;
                s_speedFiltInit = 1;
            } else {
                s_speedL_f += SPEED_FILT_ALPHA * (speedL - s_speedL_f);
                s_speedR_f += SPEED_FILT_ALPHA * (speedR - s_speedR_f);
            }

            lastControlMs = nowMs;
            
            if (!running) {
                Motor_SetSpeedBoth(0, 0);
                continue;
            }
        
            {
                uint8_t active = (uint8_t)(~ir_raw);  /* 1=触发 */
                int16_t sum = 0;
                uint8_t count = 0;
                uint8_t i;
                float trackError = 0;
                float turnOutput;
                float spdL_filt, spdR_filt;
                float pwmL, pwmR;
                float logTurnOutput = 0.0f;
                float logDynBaseSpd = 0.0f;
                uint8_t logFlags = 0;
                uint8_t logSatInfo = 0;
                float logKpScale = 1.0f;
                float errSpdL = 0.0f;
                float errSpdR = 0.0f;
                static float lastTrackError = 0;
                static uint8_t lostLineFrames = 0;  /* 连续丢线帧数 */

                /*---------- 第一步：计算循迹误差 ----------*/
                for (i = 0; i < 8; i++) {
                    if (active & (1U << (7 - i))) {
                        sum += SENSOR_WEIGHTS_V5[i];
                        count++;
                    }
                }
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

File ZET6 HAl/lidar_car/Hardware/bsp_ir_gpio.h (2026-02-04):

/**
 * @file    bsp_ir_gpio.h
 * @brief   8路红外循迹 GPIO 直接读取驱动
 * @note    使用 PF1-PF4, PF6-PF9 (跳过 PF5)
 *          读取时间 < 1μs，比 I2C 快 1000 倍！
 */

#ifndef __BSP_IR_GPIO_H
#define __BSP_IR_GPIO_H

#include "stm32f10x.h"

/*====================================================================================*/
/*                              引脚定义                                               */
/*====================================================================================*/

/* 使用 GPIOF */
#define IR_GPIO_PORT        GPIOF
#define IR_GPIO_CLK         RCC_APB2Periph_GPIOF

/* 8路传感器引脚 (从左到右: L1-L8) */
/* 注意：跳过 PF5 */
#define IR_PIN_L1           GPIO_Pin_1      /* PF1 - 最左 */
#define IR_PIN_L2           GPIO_Pin_2      /* PF2 */
#define IR_PIN_L3           GPIO_Pin_3      /* PF3 */
#define IR_PIN_L4           GPIO_Pin_4      /* PF4 */
#define IR_PIN_L5           GPIO_Pin_6      /* PF6 - 跳过PF5 */
#define IR_PIN_L6           GPIO_Pin_7      /* PF7 */
#define IR_PIN_L7           GPIO_Pin_8      /* PF8 */
#define IR_PIN_L8           GPIO_Pin_9      /* PF9 - 最右 */

/* 所有引脚掩码 */
#define IR_ALL_PINS         (IR_PIN_L1 | IR_PIN_L2 | IR_PIN_L3 | IR_PIN_L4 | \
                             IR_PIN_L5 | IR_PIN_L6 | IR_PIN_L7 | IR_PIN_L8)

/*====================================================================================*/
/*                              函数声明                                               */
/*====================================================================================*/

/**
 * @brief  初始化 GPIO 循迹模块
 */
void IR_GPIO_Init(void);

/**
 * @brief  读取 8 路循迹传感器
 * @return 8 位数据，每位代表一个传感器
 *         bit7=L1(最左), bit0=L8(最右)
 *         0=检测到黑线, 1=白色/无线
 * @note   读取时间 < 1μs
 */
uint8_t IR_GPIO_Read(void);

/**
 * @brief  读取单个传感器
 * @param  index: 0-7 (L1-L8)
 * @return 0=检测到黑线, 1=白色
 */
uint8_t IR_GPIO_ReadSingle(uint8_t index);

#endif /* __BSP_IR_GPIO_H */

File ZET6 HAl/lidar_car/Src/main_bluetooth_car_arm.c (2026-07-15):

/**
 ******************************************************************************
 * @file    main_bluetooth_car_arm.c
 * @brief   Bluetooth-controlled mecanum car and bus-servo action-group image.
 *
 * USART3 full remap: PD8=TX, PD9=RX, Bluetooth module, 9600 8N1.
 * UART4: PC10=TX, PC11=RX, bus-servo controller, 115200 8N1.
 *
 * Drive mode commands: I/S/0 arm+stop; F/G forward; B/K reverse; L/H left;
 * R/J right; Q rotate-left; E rotate-right.  P enters action mode and stops.
 * Action mode commands: 0/I initial; 1/G grab; 2/O open; 3/U lift;
 * 4/D lower; 5/K stack.  P/X returns to drive mode; S stops all servos.
 ******************************************************************************
 */

#include "app_bluetooth_motor_test.h"
#include "app_ladrc.h"
#include "app_servo_test.h"
#include "bsp_diag_uart.h"
#include "bsp_gyro_wit.h"
#include "bsp_mecanum.h"
#include "bsp_motor_safe.h"
#include "bsp_robot_uart.h"

#ifndef BLUETOOTH_BAUDRATE
#define BLUETOOTH_BAUDRATE 9600U
#endif

#define DIAG_BAUDRATE 115200U
#ifndef GYRO_BAUDRATE
#define GYRO_BAUDRATE 9600U
#endif
#define LADRC_TARGET_TENTHS          0
#define LADRC_KP_NUMERATOR           1
#define LADRC_KP_DENOMINATOR         10
#define LADRC_REPORT_INTERVAL_MS   100U
#define ACTION_SEQUENCE_TIMEOUT_MS 120U
#define ACTION_SEQUENCE_MAX_LENGTH   4U
#define ACTION_REPEAT_INTERVAL_MS      2500U
#define ACTION_REPEAT_ARM_WINDOW_MS     800U
#define ACTION_REPEAT_IDLE_TIMEOUT_MS   900U

static volatile uint32_t s_uptimeMs = 0U;
static uint8_t s_actionMode = 0U;
static uint8_t s_repeatActionActive = 0U;
static uint8_t s_repeatActionCommand = 0U;
static uint8_t s_lastActionCommand = 0U;
static uint32_t s_lastActionCommandMs = 0U;
static uint32_t s_lastRepeatTriggerMs = 0U;
static uint32_t s_nextRepeatActionMs = 0U;
static LadrcController_t s_yawLadrc;
static int16_t s_yawBaselineTenths = 0;
static uint8_t s_yawBaselineValid = 0U;
static uint8_t s_ladrcMotionActive = 0U;
static uint32_t s_lastLadrcReportMs = 0U;
static uint8_t s_actionSequence[ACTION_SEQUENCE_MAX_LENGTH];
static uint8_t s_actionSequenceLength = 0U;
static uint32_t s_actionSequenceLastMs = 0U;

typedef struct
{
    const char *wireSequence;
    uint8_t servoCommand;
} BluetoothActionSequence_t;

/* Lower-case phone button payloads, parsed atomically before drive commands. */
static const BluetoothActionSequence_t s_actionSequences[] =
{
    {"ZQ",   (uint8_t)'G'}, /* grab */
    {"FK",   (uint8_t)'O'}, /* open */
    {"JQL",  (uint8_t)'U'}, /* lift */
    {"FYD",  (uint8_t)'D'}, /* lower */
    {"DJ",   (uint8_t)'K'}, /* stack */
    {"HDCS", (uint8_t)'I'}  /* initial */
};

static void BluetoothCarArm_HandleStandardCommand(uint8_t command,
                                                   uint32_t nowMs);

void SysTick_Handler(void)
{
    ++s_uptimeMs;
}

static uint8_t BluetoothCarArm_RestoreSysTick(void)
{
    /* ServoTest uses short blocking frame gaps through Delay_ms(). */
    return (SysTick_Config(SystemCoreClock / 1000U) == 0U) ? 1U : 0U;
}

static uint8_t BluetoothCarArm_Normalize(uint8_t command)
{
    if ((command >= (uint8_t)'a') && (command <= (uint8_t)'z'))
    {
        command = (uint8_t)(command - (uint8_t)'a' + (uint8_t)'A');
    }
    return command;
}

static int16_t BluetoothCarArm_AngleDeltaTenths(int16_t current,
                                                int16_t baseline)
{
    int32_t delta = (int32_t)current - (int32_t)baseline;

    while (delta > 1800)
    {
        delta -= 3600;
    }
    while (delta < -1800)
    {
        delta += 3600;
    }
    return (int16_t)delta;
}

static void BluetoothCarArm_UpdateLadrc(uint32_t nowMs)
{
    const GyroWitState_t *gyro = GyroWit_GetState();
    int16_t yawDelta = 0;
    int16_t output;

    if (BluetoothMotorTest_IsMotionActive() == 0U)
    {
        s_ladrcMotionActive = 0U;
        return;
    }

    if (s_ladrcMotionActive == 0U)
    {
        s_ladrcMotionActive = 1U;
        s_yawBaselineTenths = gyro->yawTenthsDeg;
        s_yawBaselineValid = (gyro->angleFrameCount != 0U) ? 1U : 0U;
        Ladrc_Reset(&s_yawLadrc, LADRC_TARGET_TENTHS, 0);
        s_lastLadrcReportMs = nowMs;
        DiagUart_WriteString("BT_LADRC_START,command=");
        DiagUart_WriteChar((char)BluetoothMotorTest_GetActiveCommand());
        DiagUart_WriteString(",yaw_baseline_tenths=");
        DiagUart_WriteInt32(s_yawBaselineTenths);
        DiagUart_WriteString(",angle_frames=");
        DiagUart_WriteUInt32(gyro->angleFrameCount);
        DiagUart_WriteString("\r\n");
    }

    if ((uint32_t)(nowMs - s_lastLadrcReportMs) < LADRC_REPORT_INTERVAL_MS)
    {
        return;
    }

    s_lastLadrcReportMs = nowMs;
    if (s_yawBaselineValid != 0U)
    {
        yawDelta = BluetoothCarArm_AngleDeltaTenths(gyro->yawTenthsDeg,
                                                     s_yawBaselineTenths);
    }
    output = Ladrc_Update(&s_yawLadrc, LADRC_TARGET_TENTHS, yawDelta);

    DiagUart_WriteString("BT_LADRC,at_ms=");
    DiagUart_WriteUInt32(nowMs);
    DiagUart_WriteString(",command=");
    DiagUart_WriteChar((char)BluetoothMotorTest_GetActiveCommand());
    DiagUart_WriteString(",target_tenths=");
    DiagUart_WriteInt32(s_yawLadrc.targetTenthsDeg);
    DiagUart_WriteString(",measured_tenths=");
    DiagUart_WriteInt32(s_yawLadrc.measuredTenthsDeg);
    DiagUart_WriteString(",estimate_tenths=");
    DiagUart_WriteInt32(s_yawLadrc.estimateTenthsDeg);
    DiagUart_WriteString(",error_tenths=");
    DiagUart_WriteInt32(s_yawLadrc.errorTenthsDeg);
    DiagUart_WriteString(",output_percent=");
    DiagUart_WriteInt32(output);
    DiagUart_WriteString(",angle_frames=");
    DiagUart_WriteUInt32(gyro->angleFrameCount);
    DiagUart_WriteString("\r\n");
}

static void BluetoothCarArm_SendBluetooth(const char *message)
{
    RobotUart_BluetoothWriteString(message);
}

static void BluetoothCarArm_StopDrive(uint32_t nowMs)
{
    /* Keep the existing motor-controller arming and timeout state coherent. */
    BluetoothMotorTest_HandleByte('B', (uint8_t)'S', nowMs);
}

static void BluetoothCarArm_PrintHelp(void)
{
    DiagUart_WriteString(
        "BT_COMBINED DRIVE:I/S/0=stop F/G=forward B/K=back L/H=left "
        "R/J=right Q/E=rotate P=actions | ACTION:0/I=initial 1/G=grab "
        "2/O=open 3/U=lift 4/D=lower 5/K=stack | SEQ:zq=grab fk=open "
        "jql=lift fyd=lower dj=stack hdcs=initial P/X=drive S=all_stop\r\n");
}
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

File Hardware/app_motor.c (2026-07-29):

、#include "app_motor.h"
#include "bsp_encoder.h"
#include "bsp_systick.h"

/*====================================================================================*/
/*                              速度环参数（循迹优化版）                               */
/*====================================================================================*/

#define MOTOR_SPEED_LOOP_ENABLE 1

/* 电机速度参数 */
#define MOTOR_SPEED_MAX_MMS     2100.0f     /* 最大速度 (mm/s) */
#define MOTOR_DEADZONE_L_PCT    4           /* 左轮死区 (%) */
#define MOTOR_DEADZONE_R_PCT    5           /* 右轮死区 (%) */

/* 速度环 PID 参数 - 简化版，提高响应 */
#define MOTOR_PID_KP            0.020f      /* 比例系数 - 稍微增大 */
#define MOTOR_PID_KI            0.005f      /* 积分系数 - 减小 */
#define MOTOR_PID_KD            0.002f      /* 微分系数 - 加入抑制震荡 */
#define MOTOR_PID_INTEGRAL_LIMIT 800.0f     /* 积分限幅 */
#define MOTOR_PID_OUTPUT_LIMIT  30.0f       /* 输出限幅 (%) - 放宽 */
#define MOTOR_PID_MAX_DT_MS     200U        /* 最大时间间隔 */

/* PWM 变化率限制 - 简化为单一值，提高响应 */
#define MOTOR_PWM_SLEW_RATE     8.0f        /* 统一变化率 - 放宽限制 */

/* 速度滤波系数 */
#define MOTOR_SPEED_FILTER_ALPHA 0.5f       /* 减弱滤波，提高响应 */

typedef struct {
    float kp;
    float ki;
    float kd;
    float integral;
    float prevError;
} MotorPid_t;

static MotorPid_t s_pidLeft;
static MotorPid_t s_pidRight;
static uint32_t s_lastUpdateMs = 0;

/* 速度滤波缓存 */
static float s_filteredSpeedL = 0.0f;
static float s_filteredSpeedR = 0.0f;

/* 上一次 PWM 输出（用于变化率限制） */
static float s_lastPwmL = 0.0f;
static float s_lastPwmR = 0.0f;

static int16_t Motor_Clamp(int16_t value, int16_t min, int16_t max)
{
    if (value > max) return max;
    if (value < min) return min;
    return value;
}

static float Motor_ClampFloat(float value, float min, float max)
{
    if (value > max) return max;
    if (value < min) return min;
    return value;
}

static void Motor_PidInit(MotorPid_t *pid)
{
    pid->kp = MOTOR_PID_KP;
    pid->ki = MOTOR_PID_KI;
    pid->kd = MOTOR_PID_KD;
    pid->integral = 0.0f;
    pid->prevError = 0.0f;
}

static void Motor_PidReset(MotorPid_t *pid)
{
    pid->integral = 0.0f;
    pid->prevError = 0.0f;
}
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

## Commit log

2026-01-10 陀螺仪 - JY301P维特九轴陀螺仪I2C驱动完成，OLED显示角度数据
2026-01-13 循迹hw_i2c
    - 新增HW_I2C.c/h: 硬件I2C2驱动（标准库版本）
    - 循迹模块使用硬件I2C读取（时序精确）
    - 支持硬件I2C与软件I2C动态切换
    - Tracking.c添加Tracking_ReadHW()等函数
    - main.c v8: 硬件I2C测试版本
    - JY301P.c/h: 陀螺仪I2C驱动完善
    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
2026-01-13 循迹耦合陀螺仪
    - main.c v9: 循迹(硬件I2C) + 陀螺仪(IOI2C) 联合测试
    - HW_I2C_Enable(): 完整重新初始化I2C2，解决切换后通信失败
    - JY301P.c: 从MyI2C改为IOI2C驱动
    - Tracking.c: 移除MyI2C依赖，使用IOI2C和HW_I2C
    - 增加错误恢复机制：连续失败3次后调用BusRecovery
    - 增加切换延时确保总线稳定
2026-01-15 综合页面计时和按键 - 双页面切换功能
    [STM32F103C8T6引脚定义.xlsx]
2026-01-16 综合页面计时和按键 - TIM2精准计时 + 双页面切换功能
2026-01-16 时钟按钮切换循迹 - 权重修正+状态提示优化
2026-01-17 三页面led，声光之前
2026-01-17 pcb连接前，声光三页面
2026-01-20 编码器之前灯光三页面切换
2026-01-21 SysTick改为核心滴答，LED PWM改TIM1，新增编码器
2026-01-21 添加MG310电机和编码器驱动 - TIM重新分配
2026-01-21 修复MD芯片无TIM6问题 - LED PWM改用TIM1中断驱动
2026-01-21 feat: 适配 MG310 PWM 电机驱动并完成开环控制测试，准备进入 PID 闭合控制阶段
2026-01-21 fix: 按键消抖后重新对齐计时
2026-01-30 电机变档
2026-02-04 有点拐弯
2026-02-12 拐弯优化
2026-02-12 OLED分帧+KD增强+Kp提前介入+丢线降速
    1. OLED分帧刷新：每次只刷1行(~120ms)，消除540ms控制盲区
    2. TRACK_KD: 0.80→1.20，抑制-3/-7振荡
    3. 非线性Kp阈值: 3.0→1.0，大误差cap 2.8x→3.5x
    4. 弯道减速斜率: 0.035→0.045，min 0.25→0.20
    5. 丢线搜索: 2档(160/130)→3档(160/140/110)
2026-02-13 成品
    基于避障版本(8dc4182)，添加外设功能+参数优化：
    - 蜂鸣器：开机/启动/终点三声播报
    - LED PWM：启动时关闭TIM6省开销，终点恢复+流水灯
    - C4短按/长按循环LED亮度四档(48/30/15/3)，修复Key2双重扫描bug
    - C5长按启停，短按切页(待机)，按压进度条显示
    - OLED两页分帧显示，运行1000ms/待机800ms刷新
    - 终点检测投票20→40帧防误停
    - 直角转向增强：减速下限0.15→0.12，预减速提前触发，转向限幅400/320→420/340，方向翻转确认5→6帧
    - Delay_ms(1)主循环节流，运行时零额外开销
    [main.c]
2026-02-17 docs: 添加项目说明文档和.gitignore
    - README.md: 器件材料表 + 12项功能特性详细说明
    - .gitignore: 排除Keil编译产物、IDE配置、PDF等大文件
2026-02-17 refactor: 清理未使用文件和旧模式代码，仅保留V7竞速版
    - 删除未使用的Hardware文件: mpu6050, MPU6050_I2C, DHT11, bsp_led,
    MyI2C, bsp_motor_iic, HW_I2C, Tracking, app_irtracking (18个文件)
    - 删除cubeZMN/, softwork/, Objects/, Listings/, build/, DebugConfig/等目录
    - 删除PDF/PPTX/XLSX参考文档和临时文件
    - 删除docs/PID_TUNING_GUIDE.md和User/旧工程配置文件
    - 重构main.c: 移除MODE==0/1/2/3的条件编译代码，仅保留MODE==4
    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
    [STM32F103C8T6引脚定义.xlsx]
2026-02-17 cleanup: 移除main.c中残留的调试模式条件编译和无用定义
    - 移除SPEED_LOOP_TUNING/DEBUG_NO_KI/DEBUG_OPEN_LOOP调试分支
    - 移除未使用的宏: SPEED_KD, MOTOR_DEADZONE, ERROR_FILT_ALPHA
    - 移除未使用的变量: lastEncoderMs, loopCount
    - 1202行 → 1123行，仅保留LOG_ENABLE开关
    [main.c]
2026-02-17 style: 重排main.c代码段落顺序
    将核心功能代码（传感器权重、PI控制、避障状态机）移到日志系统之前，
    代码结构更清晰：参数定义 → 核心功能 → 日志系统 → main()
2026-02-17 docs: 更新README匹配当前V7版代码
    - 移除BOM中未使用的陀螺仪(JY301P)
    - OLED: 4页面→2页面(循迹实时页+参数页)
    - 按键: PC4更新为运行中急停/待机4档亮度
    - LED: 更新为4档亮度(48/30/15/3)
    - 移除已删除的功能: 陀螺仪姿态感知、多模式编译支持
    - 功能编号从12项调整为10项
2026-02-17 docs: 新增项目结构与主函数时序说明
    补充README的项目结构章节，按模块映射功能与实现文件，新增主循环时序、参数调参入口、以及main.c流程拆解，便于后续维护与调参定位。
2026-07-13 checkpoint: verify four-wheel motor directions
2026-07-14 feat(lidar-car): add Nano UART and Bluetooth motor test firmware
    [bluetooth_mecanum_test_template_20260713.csv, front_reverse_order_driver_fail_20260712.csv, front_static_enable_driver_chain_fail_20260712.csv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]
2026-07-15 feat(lidar-car): add bluetooth arm control and gyro diagnostics
2026-07-15 backup(lidar-car): add 3d models and nano workspace
    [10mm铜柱.SLDPRT, 60mm铜柱.SLDPRT, DG_130.stp.sldprt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]
2026-07-29 checkpoint: motor pcb and workspace baseline 20260729
    [claude-config-location.txt]
2026-07-29 test: add four-wheel TB6612 bring-up
2026-07-30 feat: verify UART5 LoRa V2.2 transport
2026-07-30 fix: gate curved A terminal by yaw progress
2026-07-30 feat: relay radar pose to ground station
2026-07-30 checkpoint: line-follow pose link and gray mapping notes
    Cache the current lidar_car working baseline: JY901 line-follow mission/observer updates, V2.2 car-pose link fields, related docs/scripts, and gray-tracking sync conclusions (x1 edge-only; center hea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
2026-07-30 checkpoint: b81 curve baseline with wireless XY invert
    Restore the verified b81e6c5 curve-control profile (drop later lost-edge history), keep LoRa CAR_POSE X/Y inversion for ground station, and record the completed line-follow flash/status baseline notes.
2026-07-31 feat(d-mission): prepare car wireless coordination
2026-07-31 feat: finalize MCU local calibration integration
